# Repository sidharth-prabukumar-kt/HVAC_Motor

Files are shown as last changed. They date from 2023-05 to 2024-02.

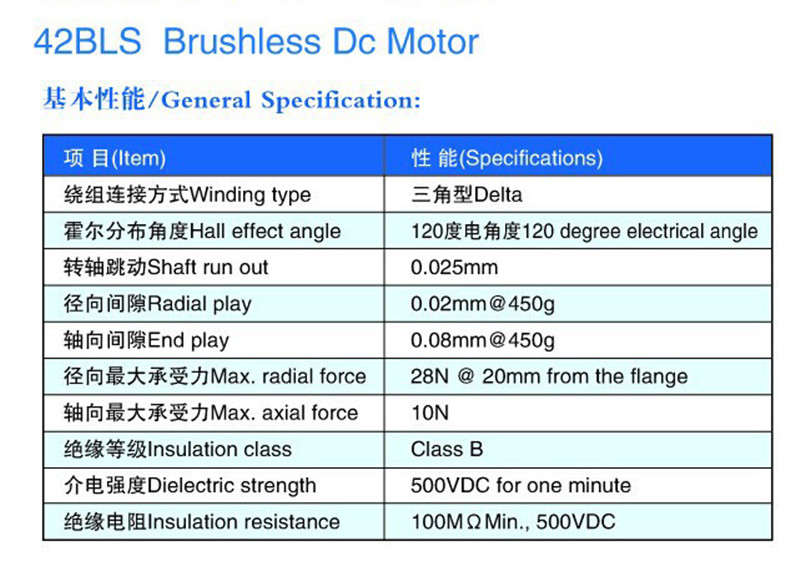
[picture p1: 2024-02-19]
Design Files/datasheets/motor_spec_1.jpg

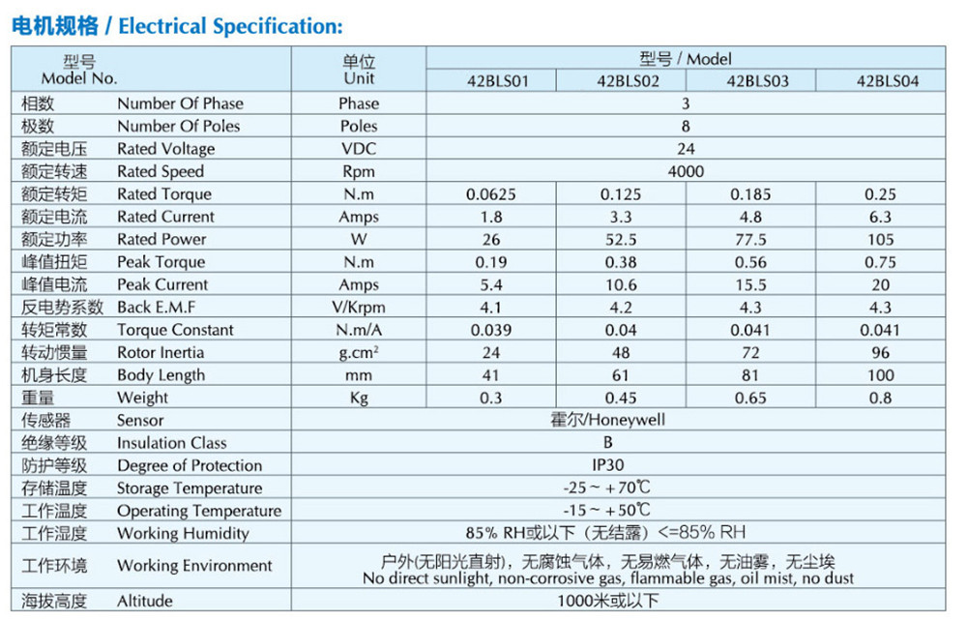
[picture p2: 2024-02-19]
Design Files/datasheets/motor_spec_2.jpg

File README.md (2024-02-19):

# HVAC Motor Project

## Overview

This project is centered around the development of an HVAC motor using a custom-designed motor controller PCB, crafted with KiCAD. The core of the software architecture is built on Zephyr RTOS, tailored with a customized device tree for optimal performance with the STM32 microcontroller.

## Features

- **Motor Control**: Utilizes PWM lines controlled by timer peripherals, interfacing with the TI *DRV8313* motor driver to manage a three-phase motor. This setup is enhanced with feedback mechanisms through current sense resistors and ADC, alongside hall effect sensors.
- **Temperature Regulation**: Incorporates a *LM75B* temperature sensor for data acquisition via I2C, regulating a surface's temperature. This surface is heated using a filament for testing purposes, simulating a real-world application.
- **Fan Implementation**: The three-phase motor is specifically deployed to drive a fan. This fan plays a role in cooling the aforementioned surface, ensuring the system remains within operational thermal limits.
- **Control Systems**: Implements two control systems:
    - A Field Oriented Control (FOC) system, leveraging feedback from the motor for precise PID loop control.
    - A temperature maintenance system, utilizing feedback from the temperature sensor to ensure the surface temperature remains within a designated range.

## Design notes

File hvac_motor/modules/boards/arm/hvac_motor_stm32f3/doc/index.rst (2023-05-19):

.. _hvac_motor_board:

HVAC Motor Controller
####################

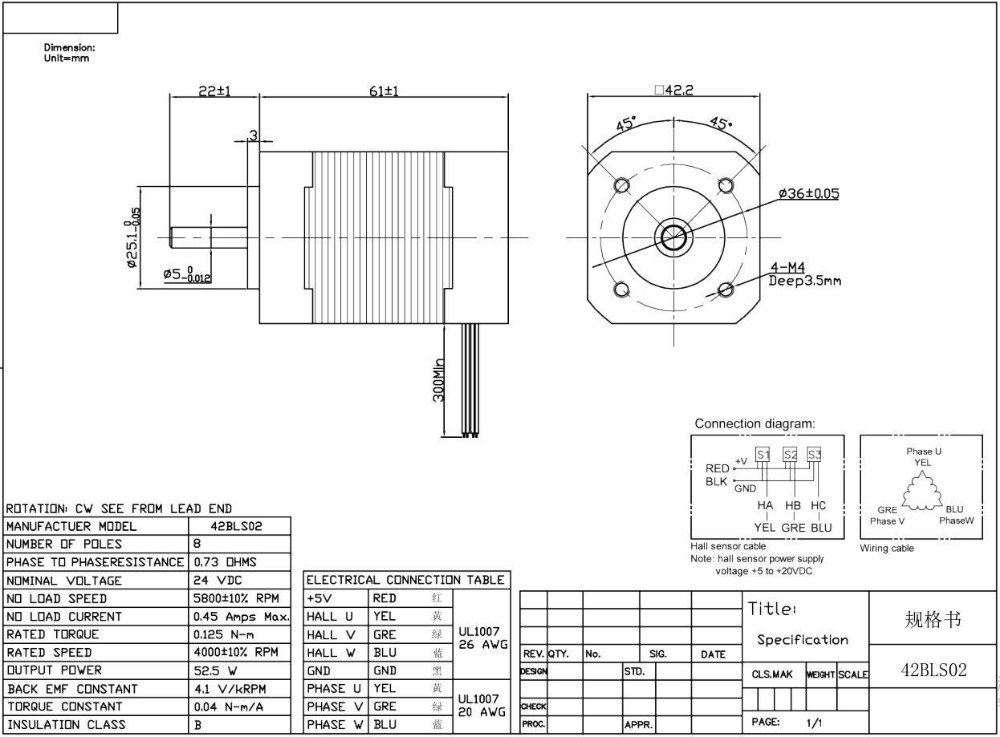
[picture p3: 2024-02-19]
Design Files/datasheets/motor_spec_3.jpg

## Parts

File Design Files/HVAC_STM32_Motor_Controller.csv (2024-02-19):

Source: | D:\KiCAD_Projects\HVAC_STM32_Motor_Controller\HVAC_STM32_Motor_Controller.kicad_sch
Date: | 5/19/2022 10:29:06 AM
Tool: | Eeschema (6.0.5)
Generator: | C:\Program Files\KiCad\6.0\bin\scripting\plugins/bom_csv_grouped_by_value_with_fp.py
Component Count: | 72
Ref | Qnty | Value | Cmp name | Footprint | Description | Vendor
C1, | 1 | 4u7 | C_Small | Capacitor_SMD:C_1206_3216Metric | Unpolarized capacitor, small symbol
C2, C3, C4, C6, C8, | 5 | 100n | C_Small | Capacitor_SMD:C_0603_1608Metric | Unpolarized capacitor, small symbol
C5, | 1 | 100u | C_Polarized_Small_US | Capacitor_SMD:CP_Elec_5x5.4 | Polarized capacitor, small US symbol
C7, | 1 | 220u | C_Polarized_Small_US | Capacitor_SMD:CP_Elec_10x10.5 | Polarized capacitor, small US symbol
C9, | 1 | 1u | C_Small | Capacitor_SMD:C_0603_1608Metric | Unpolarized capacitor, small symbol
C10, | 1 | 10n | C_Small | Capacitor_SMD:C_0603_1608Metric | Unpolarized capacitor, small symbol
C11, C12, | 2 | 10p | C_Small | Capacitor_SMD:C_0603_1608Metric | Unpolarized capacitor, small symbol
C13, | 1 | 10u | C_Polarized_Small_US | Capacitor_SMD:CP_Elec_6.3x5.4 | Polarized capacitor, small US symbol
C14, | 1 | 100n | C_Small | Capacitor_SMD:C_1206_3216Metric | Unpolarized capacitor, small symbol
C15, C17, C18, | 3 | 10n | C_Small | Capacitor_SMD:C_1206_3216Metric | Unpolarized capacitor, small symbol
C16, | 1 | 470n | C_Small | Capacitor_SMD:C_0603_1608Metric | Unpolarized capacitor, small symbol
D1, | 1 | WHITE | LED_Small | LED_SMD:LED_0603_1608Metric | Light emitting diode, small symbol
D2, D3, | 2 | SS54 | D_Schottky_Small | Diode_SMD:D_SMA | Schottky diode, small symbol
D4, | 1 | RED | LED_Small | LED_SMD:LED_0603_1608Metric | Light emitting diode, small symbol
F1, | 1 | 5A | Polyfuse | Fuse:Fuse_2010_5025Metric | Resettable fuse, polymeric positive temperature coefficient
H1, H2, H3, H4, | 4 | MountingHole_Pad | MountingHole_Pad | MountingHole:MountingHole_2.2mm_M2_Pad | Mounting Hole with connection
J1, | 1 | SWD | Conn_02x05_Odd_Even | Connector_IDC:IDC-Header_2x05_P2.54mm_Vertical | Generic connector, double row, 02x05, odd/even pin numbering scheme (row 1 odd numbers, row 2 even numbers), script generated (kicad-library-utils/schlib/autogen/connector/)
J2, | 1 | Comms | Conn_01x10 | Connector_PinHeader_2.54mm:PinHeader_1x10_P2.54mm_Vertical | Generic connector, single row, 01x10, script generated (kicad-library-utils/schlib/autogen/connector/)
J3, | 1 | 24V IN | Screw_Terminal_01x02 | TerminalBlock:TerminalBlock_Altech_AK300-2_P5.00mm | Generic screw terminal, single row, 01x02, script generated (kicad-library-utils/schlib/autogen/connector/)
J5, | 1 | USB_B_Micro | USB_B_Micro | Connector_USB:USB_Micro-AB_Molex_47590-0001 | USB Micro Type B connector
J6, | 1 | MOTOR | Screw_Terminal_01x03 | TerminalBlock:TerminalBlock_Altech_AK300-3_P5.00mm | Generic screw terminal, single row, 01x03, script generated (kicad-library-utils/schlib/autogen/connector/)
J7, | 1 | HALL FB | Screw_Terminal_01x05 | TerminalBlock_Altech:Altech_AK300_1x05_P5.00mm_45-Degree | Generic screw terminal, single row, 01x05, script generated (kicad-library-utils/schlib/autogen/connector/)
J9, | 1 | 5V OUT | Screw_Terminal_01x02 | TerminalBlock:TerminalBlock_Altech_AK300-2_P5.00mm | Generic screw terminal, single row, 01x02, script generated (kicad-library-utils/schlib/autogen/connector/)
L1, | 1 | 68u | L_Small | Inductor_SMD:L_Taiyo-Yuden_NR-30xx | Inductor, small symbol
L2, | 1 | 39n | L_Small | Inductor_SMD:L_0603_1608Metric | Inductor, small symbol
Q1, | 1 | AO3401A | AO3401A | Package_TO_SOT_SMD:SOT-23 | -4.0A Id, -30V Vds, P-Channel MOSFET, SOT-23
R1, R9, R14, R16, R17, R18, R19, R20, | 8 | 1.5k | R_Small | Resistor_SMD:R_0805_2012Metric | Resistor, small symbol
R2, R5, | 2 | 10k | R_Small | Resistor_SMD:R_0603_1608Metric | Resistor, small symbol
R3, | 1 | 10 | R_Small | Resistor_SMD:R_1206_3216Metric | Resistor, small symbol
R4, | 1 | 20 | R_Small | Resistor_SMD:R_1206_3216Metric | Resistor, small symbol
R6, R8, | 2 | 2.2k | R_Small | Resistor_SMD:R_0603_1608Metric | Resistor, small symbol
R7, | 1 | 47 | R_Small | Resistor_SMD:R_0805_2012Metric | Resistor, small symbol
R10, R11, R15, | 3 | 0.02 | R_Small | Resistor_SMD:R_1206_3216Metric | Resistor, small symbol
R12, R13, | 2 | 10k | R_Small | Resistor_SMD:R_1206_3216Metric | Resistor, small symbol
SW1, | 1 | SW_SPDT | SW_SPDT | Button_Switch_SMD:SW_SPDT_PCM12 | Switch, single pole double throw
TP1, TP4, TP5, TP6, TP7, | 5 | nFAULT | TestPoint | TestPoint:TestPoint_Pad_1.5x1.5mm | test point
U1, | 1 | STM32F302C8Tx | STM32F302C8Tx | Package_QFP:LQFP-48_7x7mm_P0.5mm | ARM Cortex-M4 MCU, 64KB flash, 16KB RAM, 72MHz, 2-3.6V, 37 GPIO, LQFP-48
U2, | 1 | XL1509-5.0E1 | XL1509 | Package_SO:SOP-8_3.9x4.9mm_P1.27mm
U3, | 1 | USBLC6-2SC6 | USBLC6-2SC6 | Package_TO_SOT_SMD:SOT-23-6 | Very low capacitance ESD protection diode, 2 data-line, SOT-23-6
U4, | 1 | DRV8313PWPR | DRV8313PWPR | Package_SO:HTSSOP-28-1EP_4.4x9.7mm_P0.65mm_EP2.85x5.4mm |  | Digikey
U5, U6, U8, | 3 | INA180 | INA180 | Package_TO_SOT_SMD:SOT-23-5
U7, | 1 | LM75B | LM75B | Package_SO:MSOP-8_3x3mm_P0.65mm | Digital Temperature Sensor & Thermal Watchdog with LP on I2C and bus fault timeout, SOIC-8 and VSSOP-8
Y1, | 1 | 16MHz | Crystal_GND24_Small | Crystal:Crystal_SMD_3225-4Pin_3.2x2.5mm | Four pin crystal, GND on pins 2 and 4, small symbol

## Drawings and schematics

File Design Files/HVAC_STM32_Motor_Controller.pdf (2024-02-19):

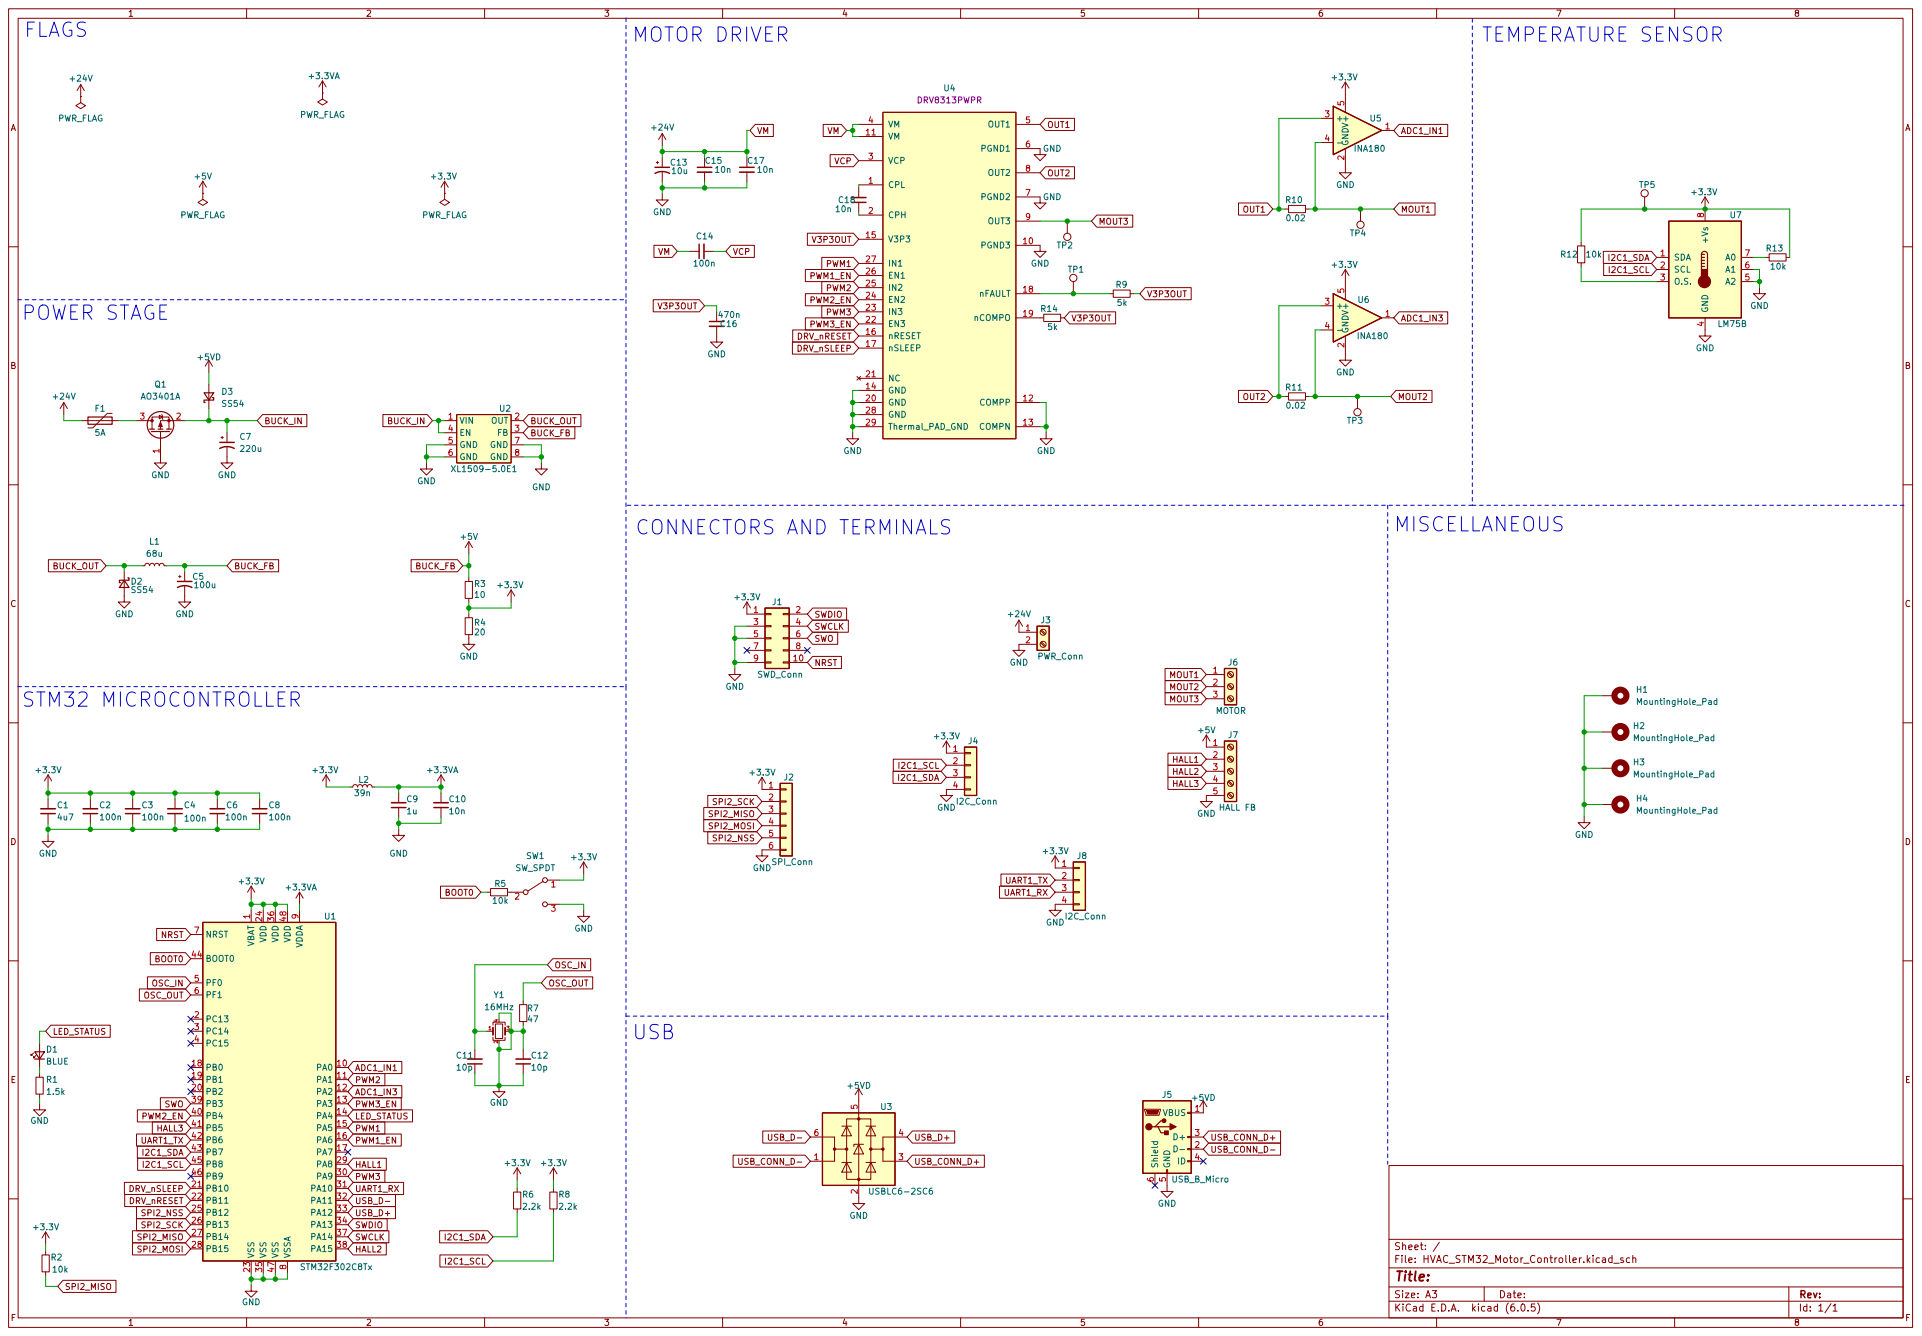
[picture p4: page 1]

1 PA0 10 PA1 11 PA2 12 PA3 13 PA4 14 PA5 15 PA6 16 PA7 17 PB0 18 PB1 19 PC13 2 PB2 20 PB10 21 PB11 22 VSS 23 VDD 24 PB12 25 PB13 26 PB14 27 PB15 28 PA8 29 PC14 3 PA9 30 PA10 31 PA11 32 PA12 33 PA13 34 VSS 35 VDD 36 PA14 37 PA15 38 PB3 39 PC15 4 PB4 40 PB5 41 PB6 42 PB7 43 BOOT0 44 PB8 45 PB9 46 VSS 47 VDD 48 PF0 5 PF1 6 NRST 7 VSSA

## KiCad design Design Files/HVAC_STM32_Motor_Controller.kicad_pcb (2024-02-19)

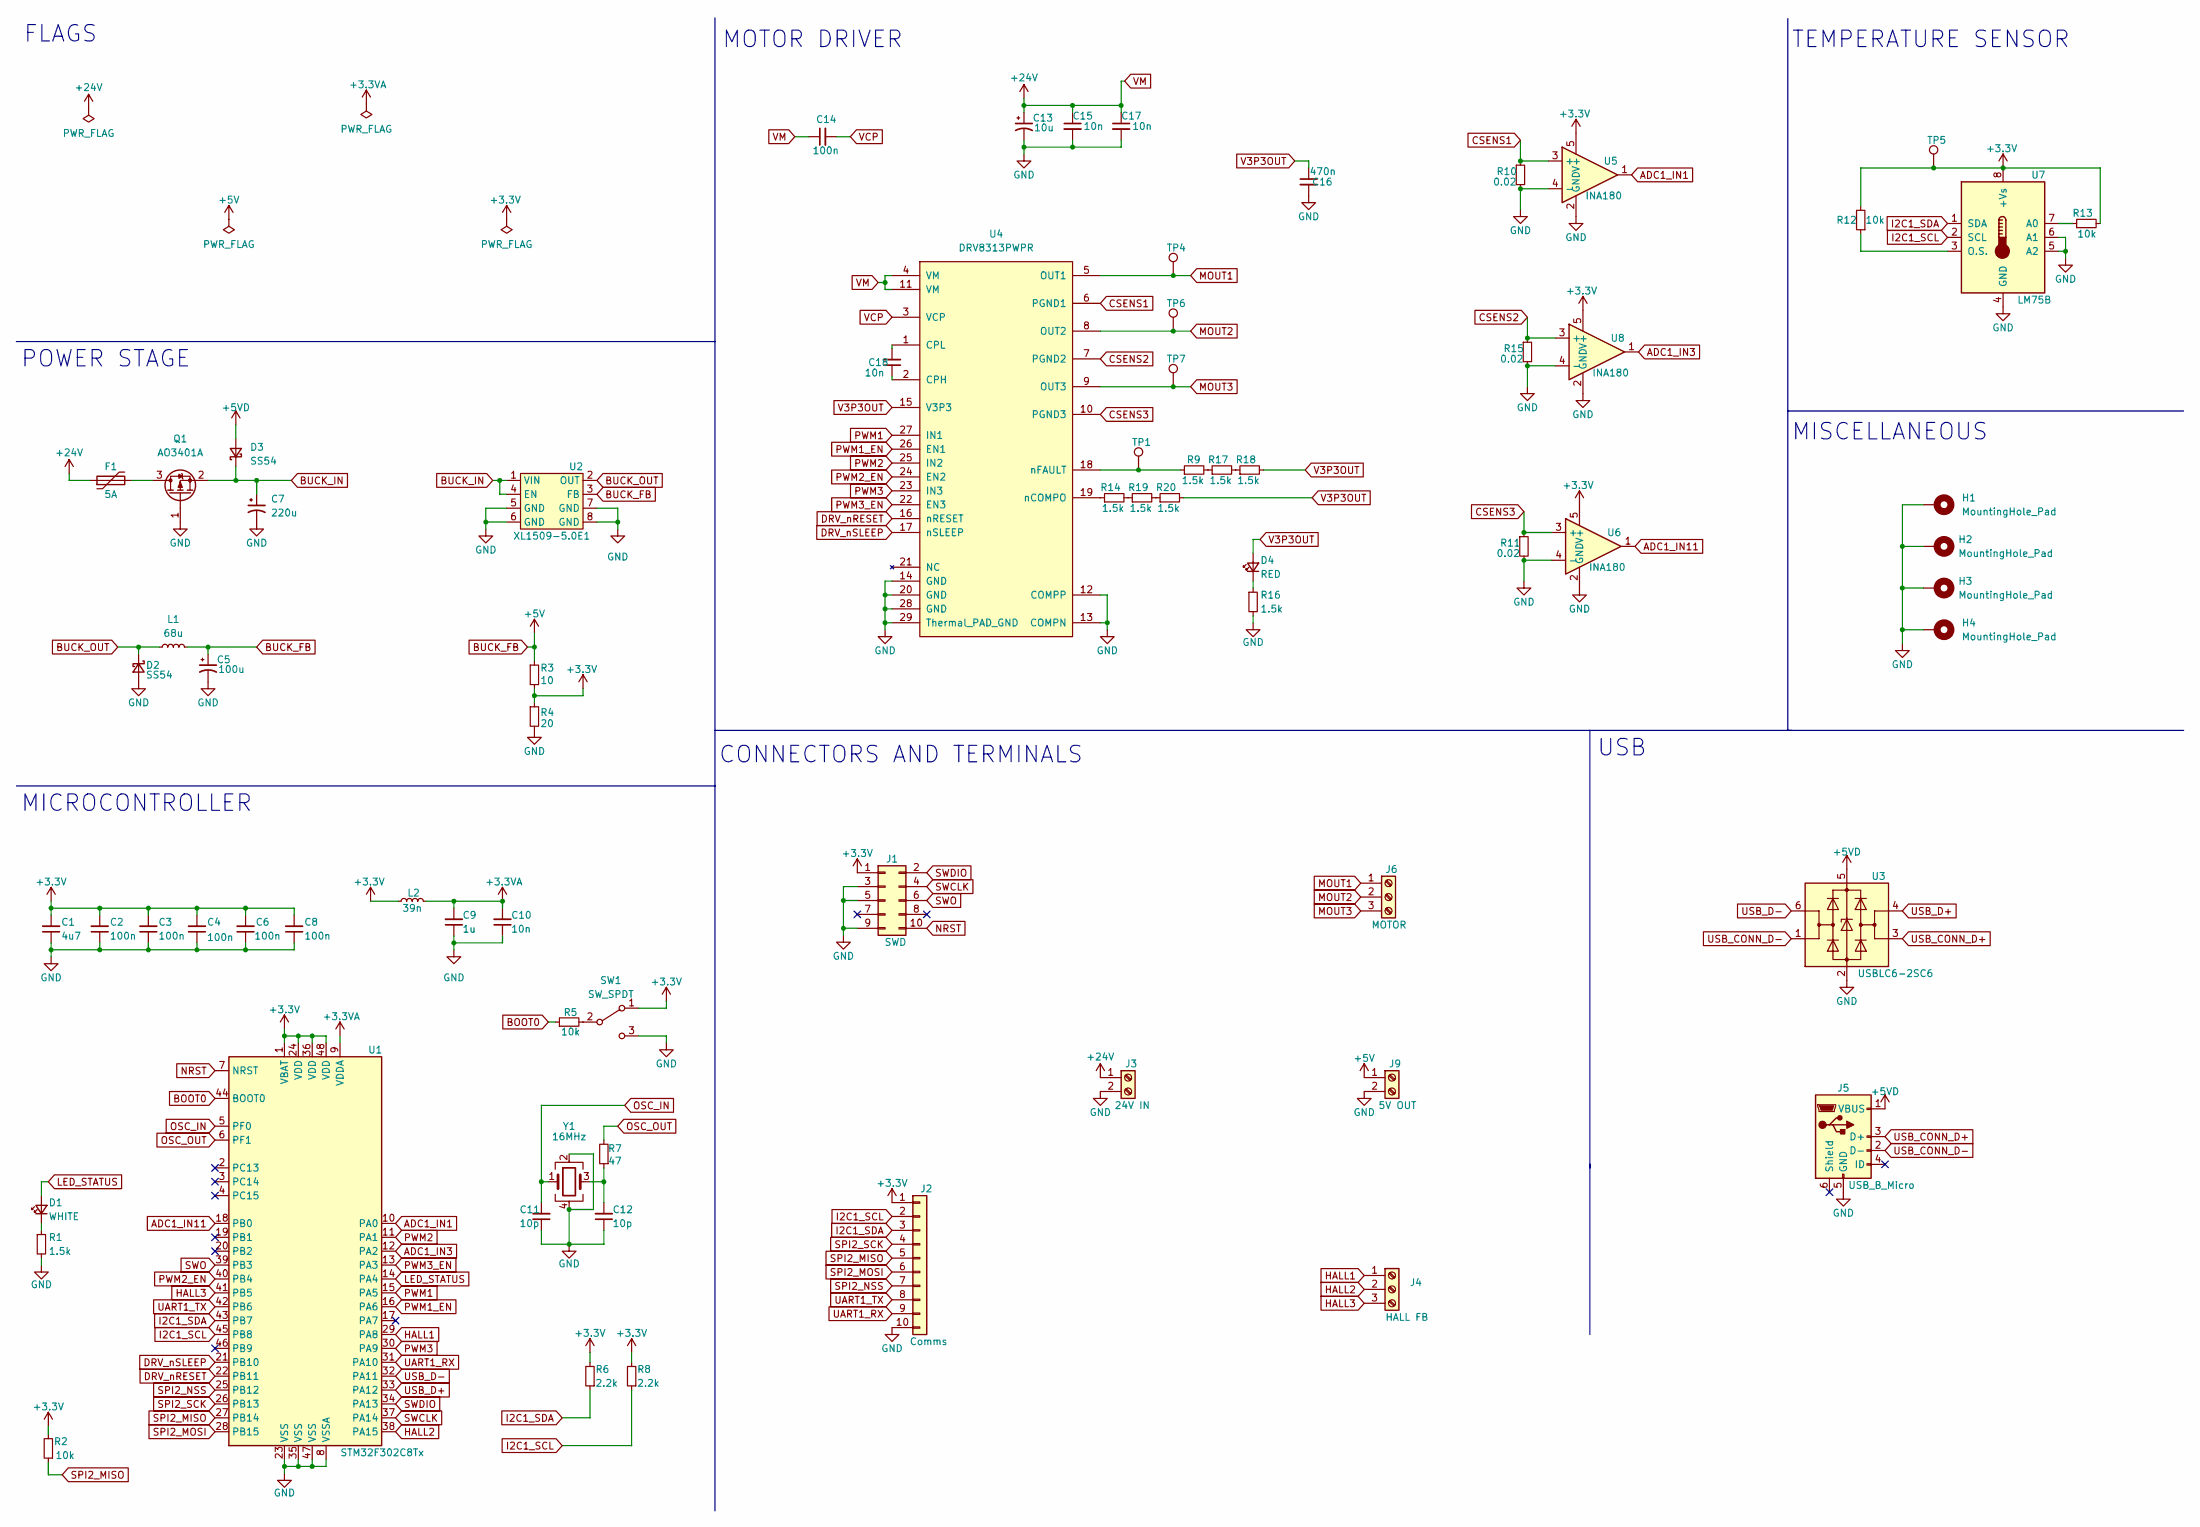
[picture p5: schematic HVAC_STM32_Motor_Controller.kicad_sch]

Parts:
C1: 4u7; C_1206_3216Metric; LCSC Part # C29823
C2, C3, C4, C6, C8: 100n; C_0603_1608Metric; LCSC Part # C14663
C5: 100u; CP_Elec_5x5.4; LCSC Part # C2891567
C7: 220u; CP_Elec_10x10.5; LCSC Part # C2887271
C9: 1u; C_0603_1608Metric; LCSC Part # C15849
C10: 10n; C_0603_1608Metric; LCSC Part # C57112
C11, C12: 10p; C_0603_1608Metric; LCSC Part # C1634
C13: 10u; CP_Elec_6.3x5.4; LCSC Part # C2836444
C14: 100n; C_1206_3216Metric; LCSC Part # C24497
C15, C17, C18: 10n; C_1206_3216Metric; LCSC Part # C1846
C16: 470n; C_0603_1608Metric; LCSC Part # C1623
D1: WHITE; LED_0603_1608Metric; LCSC Part # C2290
D2, D3: SS54; D_SMA; LCSC Part # C22452
D4: RED; LED_0603_1608Metric; LCSC Part # C2286
F1: 5A; Fuse_2010_5025Metric; LCSC Part # C48467
H1, H2, H3, H4: MountingHole_Pad; MountingHole_2.2mm_M2_Pad
J1: SWD; IDC-Header_2x05_P2.54mm_Vertical; LCSC Part # C225477
J2: Comms; PinHeader_1x10_P2.54mm_Vertical; LCSC Part # C2905488
J3: 24V IN; TerminalBlock_Altech_AK300-2_P5.00mm; LCSC Part # C3703
J4: HALL FB; TerminalBlock_Altech_AK300-3_P5.00mm; LCSC Part # C8401
J5: USB_B_Micro; USB_Micro-B_Molex-105017-0001; LCSC Part # C10418
J6: MOTOR; TerminalBlock_Altech_AK300-3_P5.00mm; LCSC Part # C8270
J9: 5V OUT; TerminalBlock_Altech_AK300-2_P5.00mm; LCSC Part # C3703
L1: 68u; L_Taiyo-Yuden_NR-30xx; LCSC Part # C83421
L2: 39n; L_0603_1608Metric; LCSC Part # C74308
Q1: AO3401A; SOT-23; LCSC Part # C15127
R1, R9, R14, R16, R17, R18, R19, R20: 1.5k; R_0805_2012Metric; LCSC Part # C4310
R2, R5: 10k; R_0603_1608Metric; LCSC Part # C25804
R3: 10; R_1206_3216Metric; LCSC Part # C17903
R4: 20; R_1206_3216Metric; LCSC Part # C17955
R6, R8: 2.2k; R_0603_1608Metric; LCSC Part # C4190
R7: 47; R_0805_2012Metric; LCSC Part # C17714
R10, R11, R15: 0.02; R_1206_3216Metric; LCSC Part # R1206
R12, R13: 10k; R_1206_3216Metric; LCSC Part # 1206
SW1: SW_SPDT; SW_SPDT_PCM12; LCSC Part # C431541
TP1, TP4, TP5, TP6, TP7: nFAULT; TestPoint_Pad_1.5x1.5mm
U1: STM32F302C8Tx; LQFP-48_7x7mm_P0.5mm; LCSC Part # C90795
U2: XL1509-5.0E1; SOP-8_3.9x4.9mm_P1.27mm; LCSC Part # C61063
U3: USBLC6-2SC6; SOT-23-6; LCSC Part # C2827654
U4: DRV8313PWPR; HTSSOP-28-1EP_4.4x9.7mm_P0.65mm_EP2.85x5.4mm; Tolerance *; Voltage 8-60V; MFR# DRV8313PWPR; LCSC Part # C92482
U5, U6, U8: INA180; SOT-23-5; LCSC Part # SOT-23-5
U7: LM75B; MSOP-8_3x3mm_P0.65mm; LCSC Part # C2837470
Y1: 16MHz; Crystal_SMD_3225-4Pin_3.2x2.5mm

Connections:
+3.3VA: C9.2, C10.2, L2.2, U1.9 (VDDA)
+3V3: C1.2, C2.2, C3.2, C4.2, C6.2, C8.2, J1.1, J2.1, L2.1, R2.2, R3.2, R4.1, R6.2, R8.2, R12.2, R13.2, SW1.1 (A), TP5.1, U1.1 (VBAT), U1.24 (VDD), U1.36 (VDD), U1.48 (VDD), U5.5 (V+), U6.5 (V+), U7.8 (+Vs), U8.5 (V+)
+5VD: D3.2 (A), J5.1 (VBUS), U3.5 (VBUS)
ADC1_IN1: U1.10 (PA0), U5.1
ADC1_IN3: U1.12 (PA2), U8.1
ADC1_IN11: U1.18 (PB0), U6.1
BOOT0: R5.1, U1.44 (BOOT0)
BUCK_FB: C5.1, J9.1, L1.2, R3.1, U2.3 (FB)
BUCK_IN: C7.1, D3.1 (K), Q1.2 (S), U2.1 (VIN), U2.4 (EN)
BUCK_OUT: D2.1 (K), L1.1, U2.2 (OUT)
CSENS1: R10.1, U4.6 (PGND1), U5.3 (+)
CSENS2: R15.1, U4.7 (PGND2), U8.3 (+)
CSENS3: R11.1, U4.10 (PGND3), U6.3 (+)
DRV_nRESET: U1.22 (PB11), U4.16 (nRESET)
DRV_nSLEEP: U1.21 (PB10), U4.17 (nSLEEP)
GND: C1.1, C2.1, C3.1, C4.1, C5.2, C6.1, C7.2, C8.1, C9.1, C10.1, C11.1, C12.1, C13.2, C15.2, C16.2, C17.2, D2.2 (A), H1.1, H2.1, H3.1, H4.1, J1.3, J1.5, J1.9, J2.10, J3.2, J5.5 (GND), J9.2, Q1.1 (G), R1.2, R4.2, R10.2, R11.2, R15.2, R16.2, SW1.3 (C), U1.8 (VSSA), U1.23 (VSS), U1.35 (VSS), U1.47 (VSS), U2.5 (GND), U2.6 (GND), U2.7 (GND), U2.8 (GND), U3.2 (GND), U4.12 (COMPP), U4.13 (COMPN), U4.14 (GND), U4.20 (GND), U4.28 (GND), U4.29 (Thermal_PAD_GND), U5.2 (GND), U5.4 (-), U6.2 (GND), U6.4 (-), U7.4 (GND), U7.5 (A2), U7.6 (A1), U8.2 (GND), U8.4 (-), Y1.2, Y1.4
HALL1: J4.1, U1.29 (PA8)
HALL2: J4.2, U1.38 (PA15)
HALL3: J4.3, U1.41 (PB5)
I2C1_SCL: J2.2, R8.1, U1.45 (PB8), U7.2 (SCL)
I2C1_SDA: J2.3, R6.1, U1.43 (PB7), U7.1 (SDA)
LED_STATUS: D1.2 (A), U1.14 (PA4)
MOUT1: J6.1, TP4.1, U4.5 (OUT1)
MOUT2: J6.2, TP6.1, U4.8 (OUT2)
MOUT3: J6.3, TP7.1, U4.9 (OUT3)
NRST: J1.10, U1.7 (NRST)
unnamed: C12.2, R7.1, Y1.3
unnamed: C18.1, U4.2 (CPH)
unnamed: C18.2, U4.1 (CPL)
unnamed: D1.1 (K), R1.1
unnamed: D4.1 (K), R16.1
unnamed: F1.2, Q1.3 (D)
unnamed: R5.2, SW1.2 (B)
unnamed: R9.1, TP1.1, U4.18 (nFAULT)
unnamed: R12.1, U7.3 (O.S.)
unnamed: R13.1, U7.7 (A0)
unnamed: R14.1, U4.19 (nCOMPO)
unnamed: R14.2, R19.1
unnamed: R9.2, R17.1
unnamed: R17.2, R18.1
unnamed: R19.2, R20.1
OSC_IN: C11.2, U1.5 (PF0), Y1.1
OSC_OUT: R7.2, U1.6 (PF1)
PWM1: U1.15 (PA5), U4.27 (IN1)
PWM1_EN: U1.16 (PA6), U4.26 (EN1)
PWM2: U1.11 (PA1), U4.25 (IN2)
PWM2_EN: U1.40 (PB4), U4.24 (EN2)
PWM3: U1.30 (PA9), U4.23 (IN3)
PWM3_EN: U1.13 (PA3), U4.22 (EN3)
SPI2_MISO: J2.5, R2.1, U1.27 (PB14)
SPI2_MOSI: J2.6, U1.28 (PB15)
SPI2_NSS: J2.7, U1.25 (PB12)
SPI2_SCK: J2.4, U1.26 (PB13)
SWCLK: J1.4, U1.37 (PA14)
SWDIO: J1.2, U1.34 (PA13)
SWO: J1.6, U1.39 (PB3)
UART1_RX: J2.9, U1.31 (PA10)
UART1_TX: J2.8, U1.42 (PB6)
USB_CONN_D+: J5.3 (D+), U3.3 (I/O2)
USB_CONN_D-: J5.2 (D-), U3.1 (I/O1)
USB_D+: U1.33 (PA12), U3.4 (I/O2)
USB_D-: U1.32 (PA11), U3.6 (I/O1)
V3P3OUT: C16.1, D4.2 (A), R18.2, R20.2, U4.15 (V3P3)
VCP: C14.2, U4.3 (VCP)
VM: C13.1, C14.1, C15.1, C17.1, F1.1, J3.1, U4.4 (VM), U4.11 (VM)

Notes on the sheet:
TEMPERATURE SENSOR
MISCELLANEOUS
POWER STAGE
MICROCONTROLLER
USB
CONNECTORS AND TERMINALS
FLAGS
MOTOR DRIVER

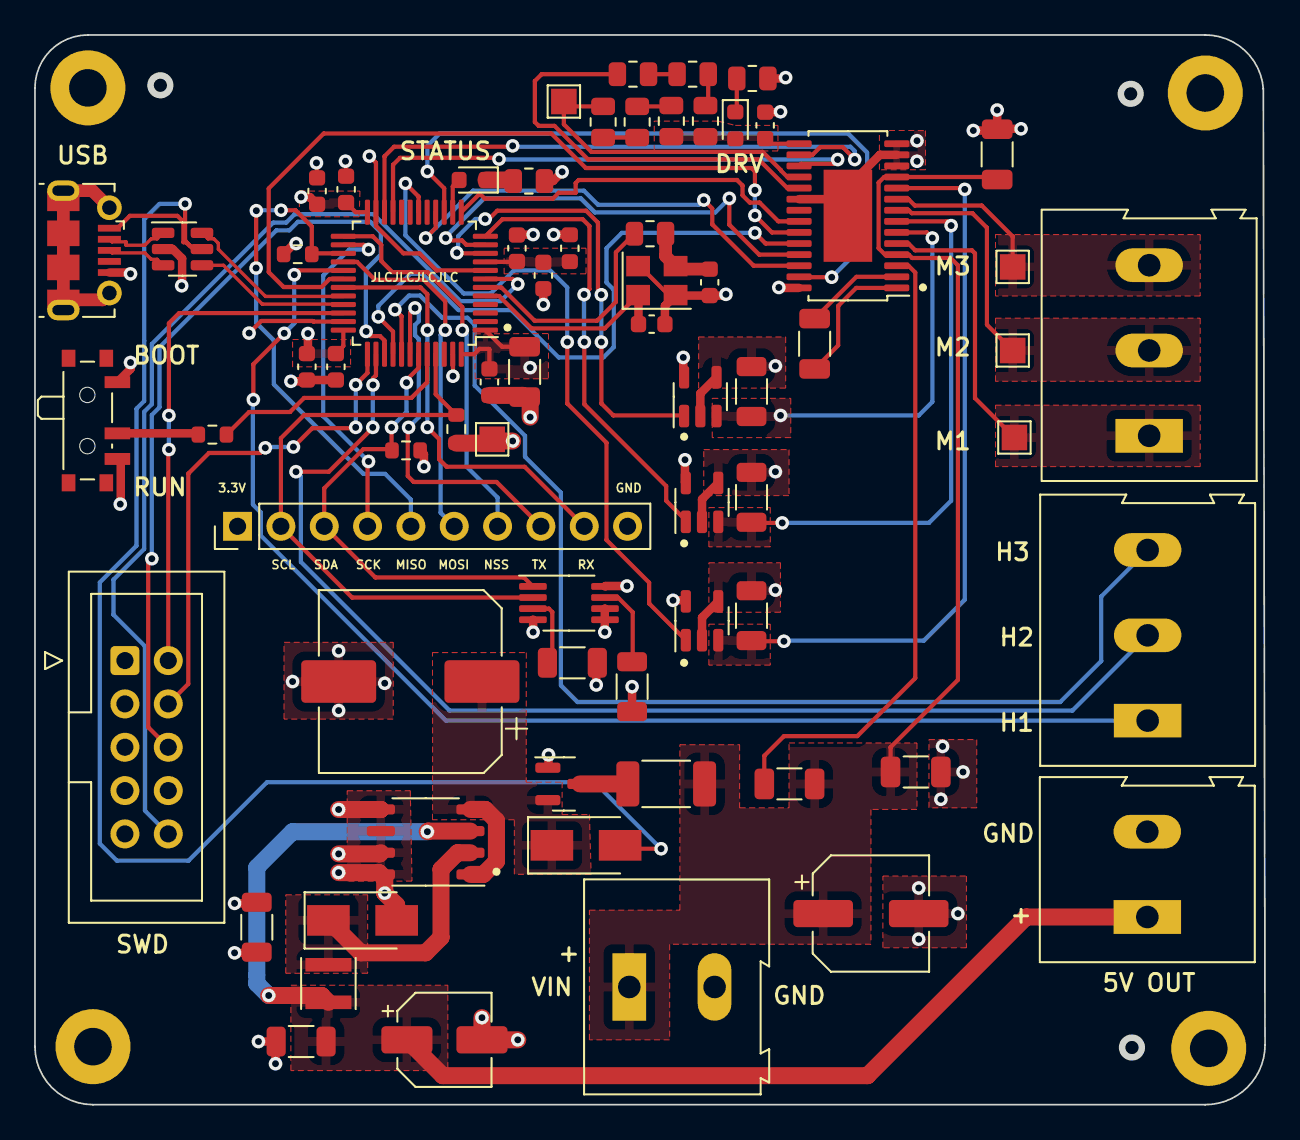
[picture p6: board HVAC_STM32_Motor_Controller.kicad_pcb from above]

Board: 4 copper layers, 72.1 x 62.7 mm, 72 parts (0 on the bottom side), 65 nets.

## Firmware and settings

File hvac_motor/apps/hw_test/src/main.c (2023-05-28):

#include <zephyr/kernel.h>
#include <zephyr/device.h>
#include <zephyr/drivers/pwm.h>

#define DT_ALIAS_PWM_0_LABEL "PWM_1"

/* period of motor signal ->  20ms (50Hz) */
#define PERIOD (NSEC_PER_SEC / 50U)

#define SLEEP_TIME_MS 500  /* Pause time in seconds*/

void main(void)
{
	printk("HVAC Motor Control - PWM Test\n");

    const struct device *pwm_dev;

	pwm_dev = device_get_binding(DT_ALIAS_PWM_0_LABEL);
	if (!pwm_dev)
	{
		printk("Cannot find PWM device!\n");
		return;
	}
	else
	{
		printk("PWM device find\n");
		printk("%s\n", DT_ALIAS_PWM_0_LABEL);
	}
	printk("PWM device cycle 1\n");
	if (pwm_set(pwm_dev, 1, PERIOD, (PERIOD * 0.9), 0))
	{
		printk("PWM pin set fails\n");
		return;
	}
	printk("PWM device cycle 2\n");
	if (pwm_set(pwm_dev, 2, PERIOD, (PERIOD * 0.5), 0))
	{
		printk("PWM pin set fails\n");
		return;
	}
	printk("PWM device cycle 3\n");
	if (pwm_set(pwm_dev, 3, PERIOD, (PERIOD * 0.3), 0))
	{
		printk("PWM pin set fails\n");
		return;
	}
    printk("Running...\n");

}

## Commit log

2023-05-19 Initial Commit: UART echo
    [hvac_motor_stm32f3.yaml]
2023-05-28 PWM Test
2024-02-19 Add PCB schematics and design files
    [BOM-HVAC_STM32_Motor_Controller.csv, HVAC_STM32_Footprint_Positions.csv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]
2024-02-19 Remove unnecessary design files
    [BOM-HVAC_STM32_Motor_Controller.csv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]
